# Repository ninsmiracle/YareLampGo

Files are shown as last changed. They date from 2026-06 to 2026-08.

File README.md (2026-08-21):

# YareLampGo

简体中文 | [English](README.en.md)

> 一盏能听、能看、会动、还会用表情回应你的开源桌面 AI 机械臂台灯。





<p align="center">
  YareLampGo V2.0 时间显示模式
  YareLampGo V2.0 海浪动作模式
</p>
<p align="center"><sub>V2.0 时间模式 · V2.0 海浪模式</sub></p>

YareLampGo 把电机、屏幕、RGB LED、摄像头、麦克风和大模型装进一盏台灯里。你可以在网页上控制它，也可以直接对它说话，或者让 Codex 帮你装机、排查问题和完成复杂任务。

## 它能做什么

- **会动，也会表达。** 5 自由度机械臂、动态眼睛和 RGB 点阵灯会一起回应，不是只会亮灯的普通台灯。
- **能看周围。** 摄像头可以拍照、巡看、找目标、检测人脸或有人出现；逗猫模式还能追踪彩色标记。
- **能听会说。** 支持语音识别、`Hi,小星` 唤醒、语音播报和实时语音对话。
- **表情可以自己做。** 网页里能直接画 51×9 LED 表情、上传眼睛动画；AI 也能按安全格式生成表情素材。
- **能把复杂任务交给 Codex。** 普通对话快速处理，复杂任务可转交本机 Codex；Codex 也能读取状态、看摄像头和调用台灯动作。
- **非技术用户也能玩。** 浏览器里就能聊天、控制动作、画表情、录制动作和改设置。
- **软件、固件、接线资料和 V2 结构总成已开源。** 支持二创和魔改；结构可自行拆分后 3D 打印。

## 有 Codex？让它带你装，也能让它接管任务

仓库自带两个 Codex skill：

- `$lampgo-setup`：根据你手上的硬件，一步步检查并执行安装。
- `$lampgo-control`：作为 LampGo 的“身体说明书”，让 Codex 只通过安全 MCP 观察、行动和验证真实结果。

macOS / Linux：

```bash
git clone https://github.com/ninsmiracle/YareLampGo.git
cd YareLampGo
./install-codex-skill.sh
```

Windows PowerShell：

```powershell
git clone https://github.com/ninsmiracle/YareLampGo.git
Set-Location YareLampGo
powershell -ExecutionPolicy Bypass -File .\install-codex-skill.ps1
```

然后新建一个 Codex 任务，直接说：

```text
用 $lampgo-setup 帮我安装和配置 YareLampGo V2.0
```

Skill 会自动判断你是“先体验软件”“已有成品机”还是“从零 DIY”。能安全执行的步骤它会直接做；写舵机 ID、烧录固件、首次接通 12V、校准和第一次真实运动前，它会停下来让你确认。中文用户默认全程中文。

设备已经运行时，也可以新建任务说：

```text
用 $lampgo-control 控制 LampGo 完成一个真实任务
```

控制 skill 只说明身体能力、安全边界和验证规则，不预设动作顺序。拍摄自主控制或模型横评时，它还提供同任务、同预算、无人干预的实验协议。

详细说明见 [Codex 集成](docs/guides/codex-integration.md)。

## 不用 Codex？也可以手动安装

不用 Codex，也可以完整手动安装。DIY 用户需要依次完成：安装软件 → 给五颗舵机写入 ID 1～5 → 烧录 S3/C6 → 断电组装和检查供电 → 扫描舵机 → 校准 → 配网并启动。

完整命令、安全检查和 Windows/macOS/Linux 说明见 [V2.0 手动安装、烧录与首次启动](docs/getting-started/manual-hardware-setup.md)。Windows x64 从零装机可直接按 [Windows x64 硬件完整流程](docs/getting-started/windows-hardware-flow.md) 执行。固件烧录以独立的 [YareLampGo_esp32](https://github.com/shelly-tang/YareLampGo_esp32) 仓库为准。

## 只想先看看软件

没有硬件也能运行 Web 控制台：

```bash
./install.sh
uv run lampgo onboard
uv run lampgo run --web --no-hw
```

浏览器打开 <http://127.0.0.1:8420>。Windows 安装命令和真实硬件装机步骤见 [快速上手](docs/getting-started/quick-start.md)。

## 常用命令

```bash
uv run lampgo help                 # 查看 CLI 说明和可复制示例
uv run lampgo detect               # 发现串口、摄像头和 ESP32
uv run lampgo setup-motors         # 自动选择或提示选择电机 COM，交互写入 ID
uv run lampgo scan-motors --auto-detect --ids 1-5
uv run lampgo ping --auto-detect
uv run lampgo calibrate --auto-detect # 交互式校准 5 个关节
uv run lampgo run --web            # 启动真实台灯和 Web 控制台
uv run lampgo run --web --no-hw    # 无硬件体验
uv run lampgo status               # 查看正在运行的服务
uv run lampgo clear                # 结束残留进程并释放电机扭矩
```

`setup-motors`、`scan-motors`、`ping` 和 `calibrate` 会优先使用显式的 `--port`，其次使用已保存的电机端口，最后自动检测。需要忽略旧配置并强制重扫时，使用 `--auto-detect`（或同义参数 `--rescan`）。多个 COM 口无法安全区分时，程序会列出候选让你确认，不会盲目写入舵机 ID。

更多参数：`uv run lampgo <command> --help`。

## 复刻 V2.0

V2.0 已直接替换 V1.0，请不要混用两代结构件、接线图或校准文件。

| 你需要的资料 | 入口 |
| --- | --- |
| Windows x64 从零装机、COM 自动检测和首次验收 | [Windows x64 硬件完整流程](docs/getting-started/windows-hardware-flow.md) |
| V2 硬件、组装和首次上电 | [V2.0 硬件与组装](docs/hardware/v2/README.md) |
| 电源、S3/C6、功放、LED 和舵机接线 | [V2.0 接线表](docs/hardware/wiring.md) |
| 完整 STEP 总成 | [V2.0 结构件](assets/printable/README.md) |
| GitHub 网页版图文组装说明 | [组装说明 Markdown](docs/hardware/v2/YareLampGo_V2.0_assembly_manual.md) |
| 原始图文组装说明 | [组装 DOCX 下载](docs/hardware/v2/YareLampGo_V2.0_assembly_manual.docx) |
| S3/C6 固件 | [YareLampGo_esp32](https://github.com/shelly-tang/YareLampGo_esp32) |

当前公开的是完整 STEP 总成，不是已经拆好的逐件 STL/3MF；电路 PNG 也是接线和走线参考，不是可以直接交给板厂的 Gerber 制板包。

## 现在可以玩什么

| 玩法 | 它会做什么 |
| --- | --- |
| [时间模式](docs/images/readme/lampgo_v2_time_mode.gif) | 点阵屏显示时间，顶部屏幕同步显示眼睛表情。 |
| [海浪模式](docs/images/readme/lampgo_v2_wave_mode.gif) | 灯头左右摆动，灯光和眼睛跟着联动。 |
| 逗猫模式 | 摄像头追踪逗猫棒上的彩色标记，根据标记附近的动作做出追踪、停顿和撤离。 |
| 音乐律动 | macOS 上可以跟随系统音频做动作。 |
| 自定义玩法 | 手动录制动作，再把动作、表情、灯光和语音组合成自己的 skill。 |

时钟、海浪和逗猫是已有能力；无声提醒、欢迎回家等场景可以继续用组合 skill 扩展。

## Codex 不只负责安装

启动 LampGo 后，它会自动发现本机 Codex 并注册 MCP 工具，不需要手动填 token 或端口：

```bash
uv run lampgo run --web
```

- 可以直接说“把 Codex 叫来”，把当前任务交给本机 Codex。
- Codex 可以读取台灯状态、调用安全动作、抓取摄像头画面或向你提问。
- `$lampgo-control` 会先验证真机、校准、急停和忙闲状态；调用成功但硬件跳过时不会冒充真实动作。
- LampGo 可以参考 Codex 的记忆摘要，也能在确认后导入 Agent 的资料和核心记忆。
- 其他 Agent 可以通过 CLI、HTTP / WebSocket API 或技能层继续接入。

## 它怎么工作

```mermaid
flowchart LR
  user["用户 / Codex"] --> entry["Web / 语音 / CLI"]
  entry --> skills["技能与任务路由"]
  skills --> safety["运动规划与安全检查"]
  safety --> hardware["电机 / 屏幕 / LED / 摄像头 / 音频"]
```

真实动作都会经过 `MotionRuntime` 和 `SafetyKernel`，再写入电机。架构细节见 [系统架构](docs/architecture.md)。

## 文档

| 想做什么 | 看这里 |
| --- | --- |
| 第一次运行 | [快速上手](docs/getting-started/quick-start.md) |
| 手动安装、烧录、舵机编号和首次上电 | [V2.0 手动安装](docs/getting-started/manual-hardware-setup.md) |
| 修改模型、语音、摄像头和设备配置 | [配置说明](docs/getting-started/configuration.md) |
| 做动作、表情和组合玩法 | [动作与表情](docs/guides/motion-and-expression.md) · [组合技能](docs/composed_skills.md) |
| 接入 Codex | [Codex 集成](docs/guides/codex-integration.md) |
| 了解项目代码 | [系统架构](docs/architecture.md) · [项目说明](docs/project_description.md) |
| 参与开发 | [贡献指南](docs/development/contributing.md) |

## 参与贡献

欢迎分享动作录制、表情、组合 skill、硬件改造和真实使用案例。一个 PR 尽量只做一件事；涉及真实硬件时，请说明使用的设备、校准、动作结果和是否测试过 `--no-hw`。

YareLampGo 是独立项目。电机控制链路使用 `lerobot[feetech]`，少量 HAL 集成工作受 LeLamp 启发，具体归属见 [NOTICE](NOTICE)。

## License

软件代码使用 [GPL-3.0-only](LICENSE)。作者与归属见 [AUTHORS.md](AUTHORS.md)、[COPYRIGHT](COPYRIGHT) 和 [NOTICE](NOTICE)。

硬件、结构、3D 模型、演示 GIF 和其他资产的许可单独列在 [ASSET_LICENSES.md](ASSET_LICENSES.md)。生产 CAD、供应商图纸、报价和工艺文件不在公开范围内，除非文件被明确列入资产许可表。

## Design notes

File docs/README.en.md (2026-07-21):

# YareLampGo Docs

[简体中文](README.md) | English

This index collects public docs for open-source users. YareLampGo turns a robotic desk lamp from lab-style hardware into a desktop companion that developers, creators, and hobbyists can make listen, see, move, and respond.

The public project name is **YareLampGo**. The `lampgo` name remains the internal short name for the CLI command, Python package, and config directory.

The root [README.md](../README.md) / [README.en.md](../README.en.md) is the quick landing page. Longer setup, configuration, motion, Codex, and development notes live under `docs/`.

Translation is being added gradually. Chinese is the default documentation language. English pages use the `README.en.md` filename convention, while deeper docs may remain Chinese until they are high enough priority to translate.

## Getting Started

| Doc | Use it for |
| --- | --- |
| [Quick Start](getting-started/quick-start.md) | First install, Web UI launch, no-hardware mode, and real hardware startup. |
| [Manual V2.0 Setup](getting-started/manual-hardware-setup.en.md) | Servo IDs, S3/C6 flashing, first power, and calibration without Codex. |
| [Configuration](getting-started/configuration.md) | `~/.lampgo/config.toml`, environment variables, credentials, and common config fields. |

## Guides

| Doc | Use it for |
| --- | --- |
| [Motion and Expression](guides/motion-and-expression.md) | Built-in motions, CSV recording/playback, LED expressions, and composed skills. |
| [Codex Integration](guides/codex-integration.md) | Zero-config local Codex handoff and LampGo MCP tools. |
| [V2.0 Hardware and Assembly](hardware/v2/README.en.md) | V2.0 electrical/PCB images, assembly guide, wiring, STEP, and first-power flow. |

## Architecture And Background

| Doc | Use it for |
| --- | --- |
| [Architecture](architecture.md) | IntentRouter, SkillExecutor, MotionRuntime, SafetyKernel, and HAL layering. |
| [Project Description](project_description.md) | Project background, capability boundary, and technical direction. |
| [Roadmap](roadmap.en.md) | Replaceable head modules, algorithm extension points, and future community work. |
| [Composed Skills](composed_skills.md) | User skill / composed skill data format and execution rules. |
| [Hardware And Asset Scope](hardware-and-assets-scope.md) | License boundary for software, firmware, 3D visualization assets, community printable files, and supplier production materials. |
| [Structure Files](../assets/printable/README.en.md) | V2.0 STEP AP214 complete assembly, preview, and fabrication limits. |

## Examples And References

| Path | Contents |
| --- | --- |
| [`examples/basic_motion.py`](../examples/basic_motion.py) | Basic motion control example. |
| [`examples/custom_skill.py`](../examples/custom_skill.py) | Custom skill example. |
| [`lampgo/mcp_stdio.py`](../lampgo/mcp_stdio.py) | Local MCP entrypoint used by Codex to call lamp capabilities. |

## Translation Policy

Chinese is the default documentation language. Default `README.md` files should stay Chinese, and English entry points should use the same-folder `README.en.md` convention. Key onboarding docs should be translated first; deeper design notes can stay in one language until there is enough demand. When changing a bilingual doc, mention in the PR whether the matching translation was updated or is pending.

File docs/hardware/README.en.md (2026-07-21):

# Hardware Guide

[简体中文](README.md) | English

V2.0 is the only maintained public YareLampGo hardware and mechanical version. V1.0 wiring, structure, and calibration data are no longer the main line and must not be mixed with V2.0.

## Current entry points

| File | Purpose |
| --- | --- |
| [V2.0 hardware and assembly](v2/README.en.md) | Release contents, six electrical/PCB image explanations, assembly order, first power, and V1 migration. |
| [V2.0 wiring](wiring.md) | Searchable 12V/+5V, S3/C6, amplifier, LED, and five-servo wiring tables. |
| [V2.0 assembly guide (web, Chinese)](v2/YareLampGo_V2.0_assembly_manual.md) | GitHub-readable BOM, wiring, fabrication, and assembly images. |
| [V2.0 assembly manual (DOCX download)](v2/YareLampGo_V2.0_assembly_manual.docx) | Original illustrated file for offline viewing or printing. |
| [V2.0 STEP structure](../../assets/printable/README.en.md) | Complete STEP AP214 assembly, preview, and usage limits. |
| [Source manifest](v2/SOURCE_MANIFEST.md) | Original names, SHA-256 values, inspection results, and publication limits. |
| [Hardware and asset scope](../hardware-and-assets-scope.md) | Licensing and publication boundary. |

## Important boundary

The PNGs explain nets, interfaces, placement, and PCB routing; they are not Gerber, drill, placement, or production-BOM files. The complete STEP is an assembly reference, not a per-part STL/3MF package. Makers remain responsible for fabrication, electrical, and first-power engineering checks.

See [ASSET_LICENSES.md](../../ASSET_LICENSES.md) for the exact asset licenses.

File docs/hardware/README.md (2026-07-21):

# 硬件公开资料

简体中文 | [English](README.en.md)

V2.0 是 YareLampGo 当前唯一维护的公开硬件和机械结构版本。V1.0 接线图、结构件与校准数据不再作为主线，也不能和 V2.0 混用。

## 当前入口

| 文件 | 说明 |
| --- | --- |
| [V2.0 硬件与组装](v2/README.md) | 发布内容、六张电路/PCB 图说明、装配顺序、首次上电和 V1 迁移。 |
| [V2.0 接线表](wiring.md) | 12V/+5V 电源域、S3/C6、功放、LED 和五颗舵机的可搜索接线表。 |
| [V2.0 组装说明（网页）](v2/YareLampGo_V2.0_assembly_manual.md) | 可直接在 GitHub 阅读的物料、线路、加工和组装图。 |
| [V2.0 组装说明（DOCX 下载）](v2/YareLampGo_V2.0_assembly_manual.docx) | 原始图文文件，适合离线查看或打印。 |
| [V2.0 STEP 结构件](../../assets/printable/README.md) | 完整 STEP AP214 总成、预览和使用边界。 |
| [源文件清单](v2/SOURCE_MANIFEST.md) | 原始文件名、SHA-256、文件检查结果和公开资料限制。 |
| [硬件与资产范围](../hardware-and-assets-scope.md) | 许可和发布边界。 |

## 重要边界

电路 PNG 用于理解网络、接口、器件位置和 PCB 走线，不是 Gerber/钻孔/坐标/生产 BOM。完整 STEP 是装配参考总成，不是已经拆好的逐件 STL/3MF。任何制造、制板和首次上电都需要制作者自行完成工程复核。

具体授权以仓库根目录的 [ASSET_LICENSES.md](../../ASSET_LICENSES.md) 为准。

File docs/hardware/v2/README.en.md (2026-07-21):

# YareLampGo V2.0 Hardware and Assembly

[简体中文](README.md) | English

V2.0 is the only maintained public hardware and mechanical version. Because V1.0 had very limited adoption, this release replaces the old structure and wiring entry points instead of supporting mixed V1/V2 assemblies.

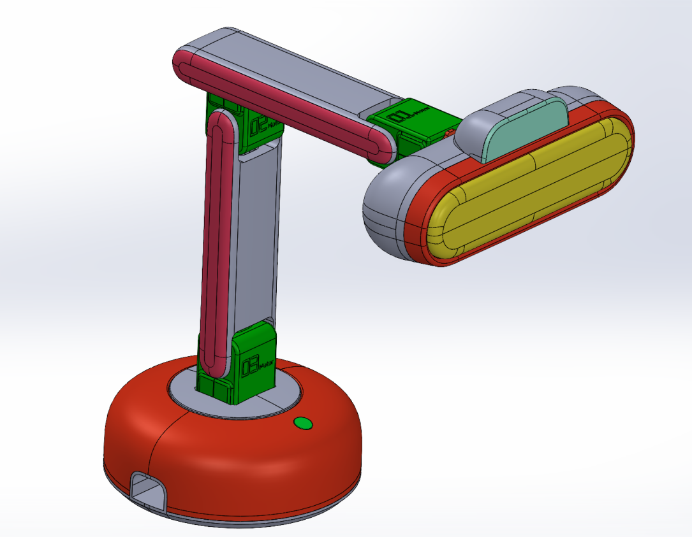
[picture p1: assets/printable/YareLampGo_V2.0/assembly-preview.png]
YareLampGo V2.0 assembly


## Release contents

| Artifact | Purpose |
| --- | --- |
| [Manual setup, flashing, and first start](../../getting-started/manual-hardware-setup.en.md) | Complete flow from servo IDs and S3/C6 flashing through calibration and Web startup. |
| [Complete STEP assembly](../../../assets/printable/YareLampGo_V2.0/YareLampGo_V2.0_assembly.step) | Structural relationships and purchased-component reference geometry; units are millimetres. |
| [GitHub-readable assembly guide (Chinese)](YareLampGo_V2.0_assembly_manual.md) | Full BOM, wiring, fabrication, and assembly images in the browser. |
| [Assembly manual DOCX download](YareLampGo_V2.0_assembly_manual.docx) | Original illustrated file for offline viewing or printing. |
| [Current wiring guide](../wiring.md) | Searchable power, S3/C6, audio, LED, and servo wiring tables. |
| [`schematics/`](schematics/) | Four schematic/interface images and top/bottom PCB reference views. |
| [Source manifest](SOURCE_MANIFEST.md) | Original names, checksums, STEP/DOCX/GIF inspection results, and publication limits. |

## Current V2.0 unit demos

<p align="center">
  YareLampGo V2.0 time display mode
  YareLampGo V2.0 wave motion mode
</p>

- **Time mode:** the front matrix displays the time while the C6 screen shows an eye expression, demonstrating the current display chain and V2.0 physical design.
- **Wave mode:** the head sweeps from side to side while the front light shows a blue bar, demonstrating calibrated joint motion coordinated with light and expression output.

These GIFs show the current V2.0 unit; they are not evidence of clock accuracy, full-range joint safety, endurance, or electrical certification. Every reproduced unit still needs its own servo scan, calibration, and motion-envelope check.

## V2.0 architecture

- Seeed Studio XIAO ESP32-S3 Sense for camera, audio, LED, network, and host communication.
- ESP32-C6-LCD-1.47 display connected to the S3 over UART.
- Five STS3215 bus servos using IDs 1 through 5.
- On-board MAX98357A audio design plus an H4 five-pin compatible amplifier-module footprint; CN7 drives the speaker.
- U3 LED connector with two +5V contacts, two ground contacts, and `DIN`.
- A 12V servo domain and a +5V logic/audio/LED domain with a shared ground.

## Electrical image map

| Image | What it establishes |
| --- | --- |
| [`01-xiao-esp32-s3-pinout.png`](schematics/01-xiao-esp32-s3-pinout.png) | GPIO1 BCLK, GPIO2 LRCLK, GPIO3 LED DIN, GPIO4 amplifier data, GPIO43/44 C6 UART, +5V/GND. |
| [`02-esp32-c6-lcd-headers.png`](schematics/02-esp32-c6-lcd-headers.png) | Crossed S3/C6 UART on U1 and VBUS/GND on U2. |
| [`03-max98357a-amplifier.png`](schematics/03-max98357a-amplifier.png) | MAX98357A power, I2S, shutdown pull-up, speaker output, and module-compatible header. |
| [`04-led-board-connector.png`](schematics/04-led-board-connector.png) | U3: GND, GND, DIN, +5V, +5V from pins 5 to 1. |
| [`05-main-board-top.png`](schematics/05-main-board-top.png) | Top-side placement and routing reference. |
| [`06-main-board-bottom.png`](schematics/06-main-board-bottom.png) | Bottom-side routing and copper reference. |

The PNGs are review aids, not a board-house package. They do not include editable EDA source, Gerbers, drill data, placement coordinates, stack-up, stencil data, a production BOM, or an electrical test report.

## Recommended assembly order

1. Assign servo IDs 1-5 before installation, with only one unconfigured servo connected at a time. Disconnect 12V before every cable change.
2. Prepare the M2.5 heat-set inserts/fasteners, M3 joint fasteners, and self-tapping screws shown in the DOCX. Verify lengths and counts against the actual parts.
3. Install the servo shells with internal cable routing; keep the three mid-arm cable exits consistent and free of pinch points.
4. With 12V and USB disconnected, install the power module, base servo, main board, and base fasteners. Route cables before closing the base.
5. Assemble the support arms with M3 fasteners, passing cables through the provided holes and checking the full joint travel.
6. Install the LED board and four retaining blocks, head ring, controller, C6 display/cover, speaker, and head shells.
7. Inspect every insert, fastener, connector orientation, clearance, and cable path before applying power.

The illustrated BOM contains image-only names and does not specify every fastener length. Treat it as an assembly reference, not an unchecked production purchasing BOM.

## First power and setup

1. Remove the S3, C6, LED, and amplifier loads. Verify 12V polarity and the power module's +5V output with a multimeter.
2. Power off, reinstall logic modules, and validate S3 and C6 firmware over USB separately.
3. Support the mechanism, keep joints away from stops, and be ready to remove 12V.
4. Install software and run read-only detection:

   ```bash
   ./install.sh
   uv run lampgo detect
   uv run lampgo scan-motors --ids 1-5
   uv run lampgo ping
   ```

5. After all five servos and directions are confirmed, back up any existing calibration and run:

   ```bash
   uv run lampgo calibrate
   uv run lampgo onboard
   uv run lampgo run --web
   ```

6. Open <http://127.0.0.1:8420>, finish 2.4 GHz Wi-Fi, LLM, voice, and Codex checks, then test a small motion before large motions.

Codex users can install the repository's [`lampgo-setup`](../../../skills/lampgo-setup/SKILL.md) skill. It offers software-only, assembled-unit, and DIY V2.0 routes and pauses before servo-ID writes, erase flashing, calibration, and first motion.

## V1.0 migration

- Do not mix V1.0 and V2.0 structural parts.
- Old wiring and print-layout images no longer represent the current board or structure.
- Existing software configuration may be used only as a field reference. Reconfirm ports, device identity, and calibration on the V2.0 unit.
- Never reuse V1.0 calibration as V2.0 calibration.

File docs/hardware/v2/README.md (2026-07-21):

# YareLampGo V2.0 硬件与组装

简体中文 | [English](README.en.md)

V2.0 是当前公开硬件和机械结构的唯一维护版本。由于 V1.0 用户量很小，本次直接替换旧结构和接线入口，不提供 V1/V2 混装兼容方案。

YareLampGo V2.0 总成

## 这次发布包含什么

| 资料 | 用途 |
| --- | --- |
| [手动安装、烧录与首次启动](../../getting-started/manual-hardware-setup.md) | 从舵机编号、S3/C6 烧录到校准和 Web 启动的完整命令流程。 |
| [完整 STEP 总成](../../../assets/printable/YareLampGo_V2.0/YareLampGo_V2.0_assembly.step) | 查看结构、装配关系和采购件占位；单位为毫米。 |
| [GitHub 网页版组装说明](YareLampGo_V2.0_assembly_manual.md) | 直接在网页查看完整物料、线路、加工和组装图片。 |
| [组装说明 DOCX 下载](YareLampGo_V2.0_assembly_manual.docx) | 原始图文文件；适合离线查看或打印。 |
| [当前接线指南](../wiring.md) | 可搜索的电源域、S3/C6、音频、LED 和舵机接线表。 |
| [`schematics/`](schematics/) | 4 张原理/接口图和 2 张 PCB 顶/底层参考图。 |
| [源文件清单](SOURCE_MANIFEST.md) | 原始文件名、SHA-256、STEP/DOCX/GIF 检查结果和发布边界。 |

## 当前 V2.0 实机展示

<p align="center">
  YareLampGo V2.0 时间显示模式
  YareLampGo V2.0 海浪动作模式
</p>

- **时间模式：** 前置点阵屏显示时间，顶部 C6 屏显示眼睛表情，用于展示当前显示链路和 V2.0 整机外观。
- **海浪模式：** 灯头左右摆动，前置灯带显示蓝色光带，用于展示校准后关节动作与灯光/表情联动。

这两段 GIF 是当前 V2.0 实机展示，不是时钟精度、关节全行程、长时间运行稳定性或电气安全测试报告。其他设备复现动作前仍需完成本机舵机扫描、校准和运动空间确认。

## V2.0 架构

- 主控：Seeed Studio XIAO ESP32-S3 Sense，负责摄像头、音频、LED、网络和上位机通信。
- 屏幕：ESP32-C6-LCD-1.47，通过 UART 与 S3 互联。
- 运动：5 颗 STS3215 总线舵机，仍使用 ID 1～5。
- 音频：MAX98357A 板载方案，并保留 H4 五针功放模块兼容接口；CN7 接喇叭。
- 灯板：U3 五针接口，包含两组 +5V/GND 和一根 `DIN`。
- 供电：舵机侧为 12V，S3/C6/功放/LED 为 +5V，全部共地。

## 电路图说明

### 1. XIAO ESP32-S3 引脚

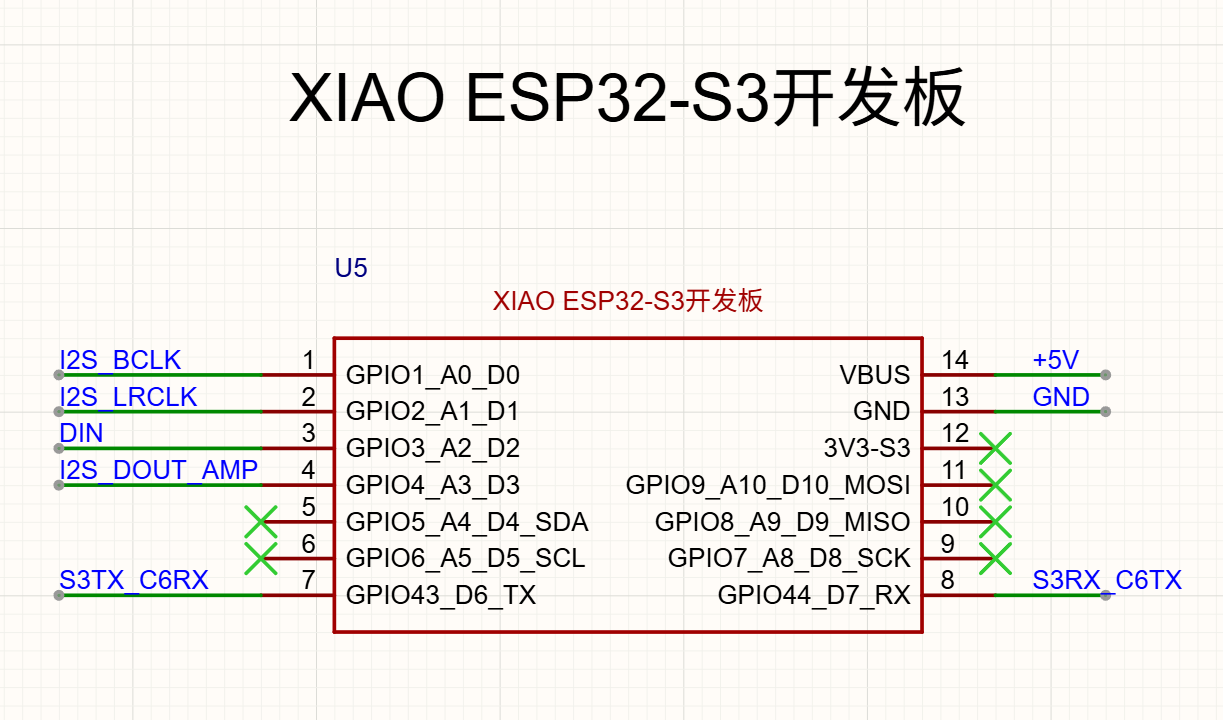
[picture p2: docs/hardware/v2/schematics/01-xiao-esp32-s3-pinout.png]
XIAO ESP32-S3 pinout


关键网络：GPIO1 为 I2S BCLK，GPIO2 为 I2S LRCLK，GPIO3 为 LED `DIN`，GPIO4 为功放 I2S 数据，GPIO43/44 为 C6 UART TX/RX。VBUS 接 +5V。

### 2. ESP32-C6 LCD 排针

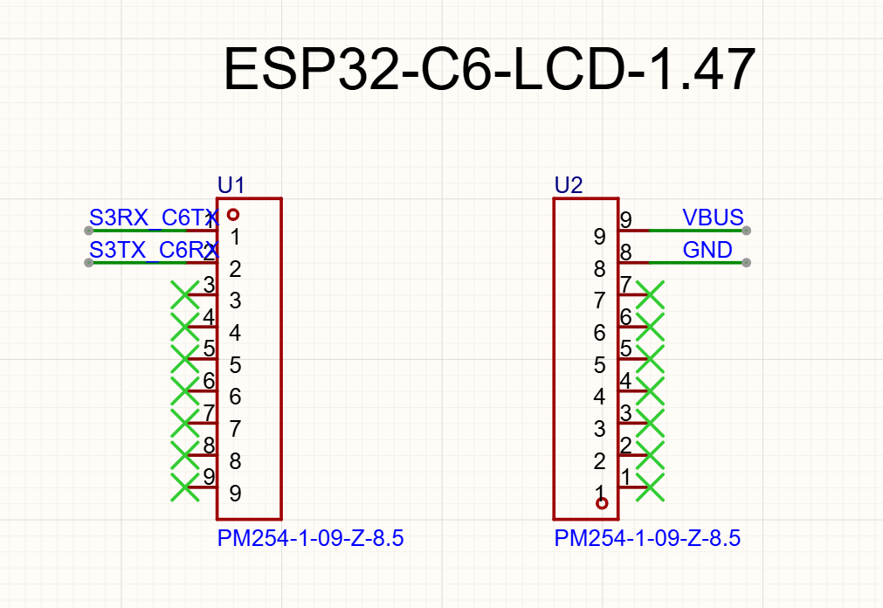
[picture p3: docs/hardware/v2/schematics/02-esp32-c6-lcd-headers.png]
ESP32-C6 LCD headers


U1 的前两针承载 S3/C6 交叉 UART；U2 的 9/8 针为 VBUS/GND。图中其余针位标记为不连接。排针网络名表达方向：`S3TX_C6RX` 是 S3 发给 C6，`S3RX_C6TX` 是 C6 发给 S3。

### 3. MAX98357A 功放

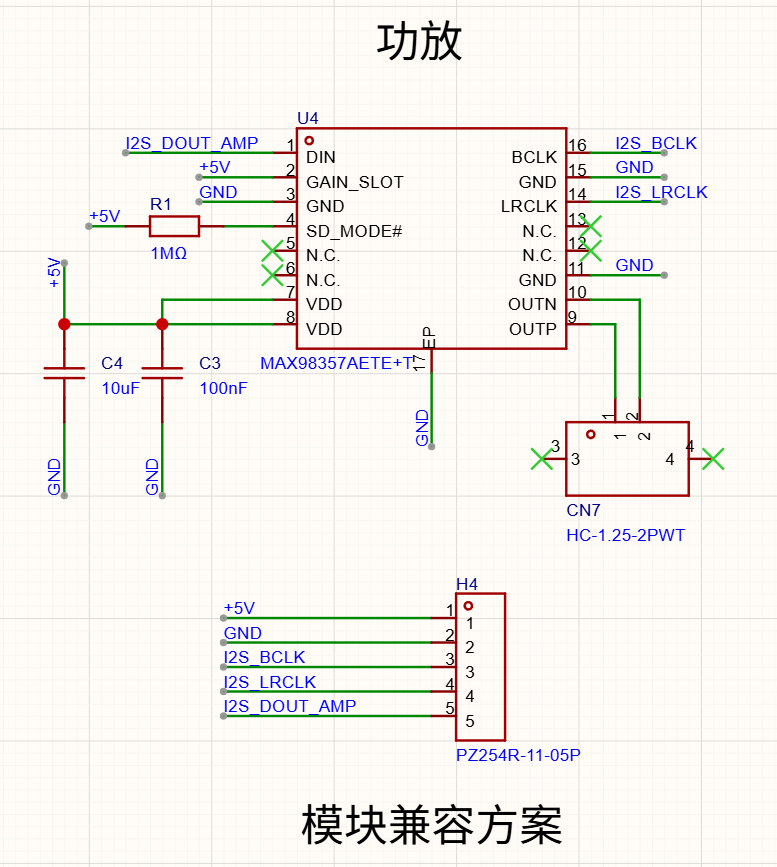
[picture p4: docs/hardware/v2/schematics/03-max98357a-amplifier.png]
MAX98357A amplifier


板载 MAX98357A 使用 +5V、BCLK、LRCLK 和 `I2S_DOUT_AMP`。`SD_MODE#` 由 1 MΩ 上拉，OUTP/OUTN 以桥接方式驱动 CN7 喇叭。H4 复用相同五个网络，用于兼容现成功放模块；不要同时装两套相互冲突的输出路径。

### 4. LED 灯板接口

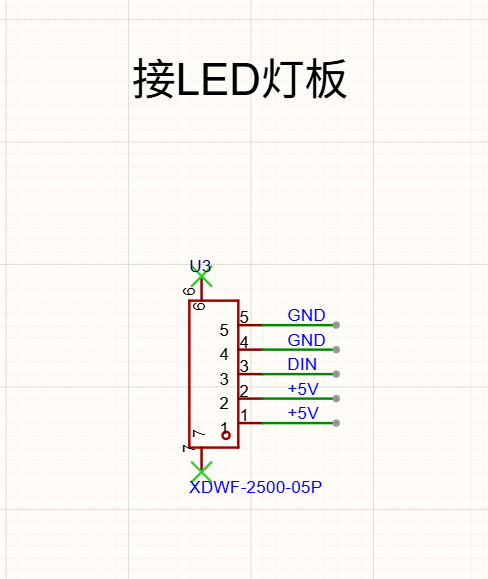
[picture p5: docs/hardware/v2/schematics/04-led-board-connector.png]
LED board connector


U3 从 5 到 1 依次为 GND、GND、DIN、+5V、+5V。此图没有定义线束插头的观察方向，压线和插接前必须对照 PCB 丝印和万用表，不要仅凭线色判断。

### 5. 主板顶层

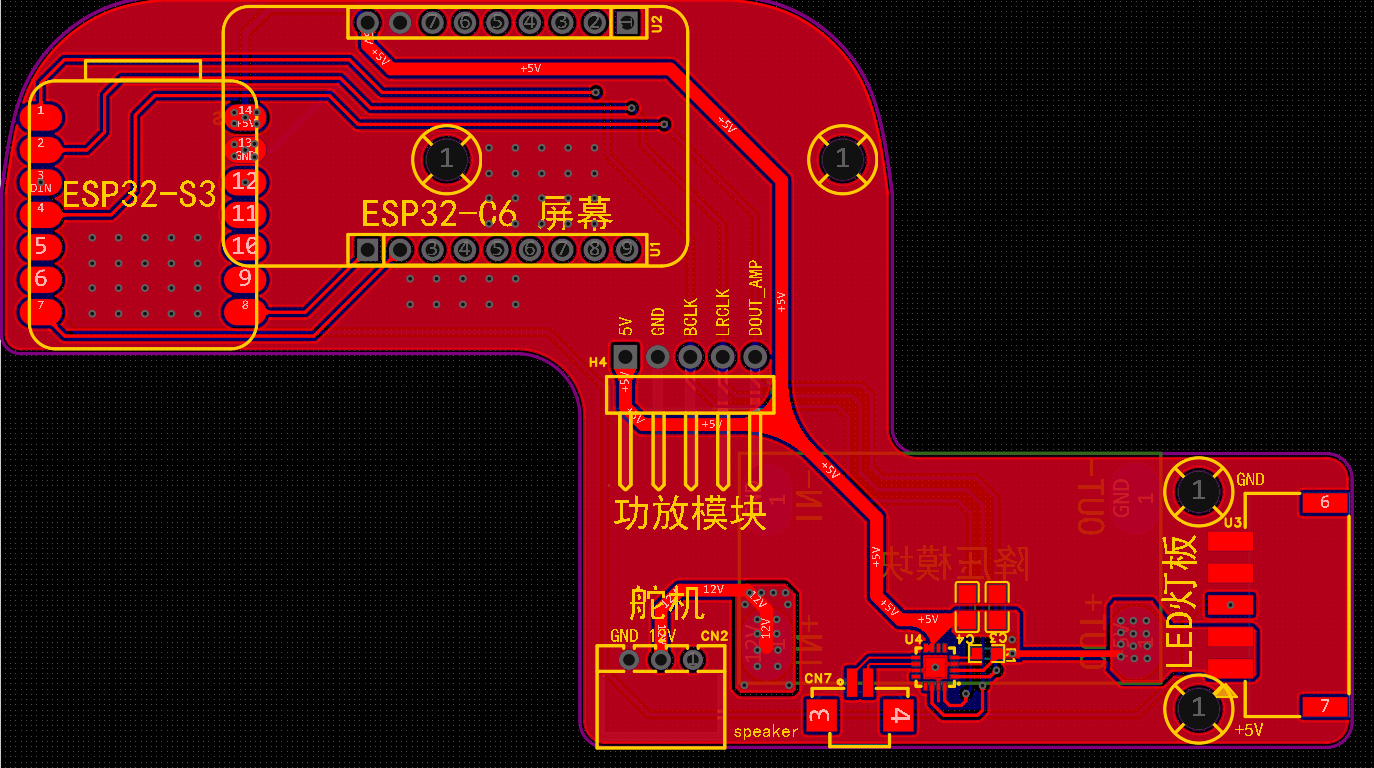
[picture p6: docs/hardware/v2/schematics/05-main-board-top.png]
Main board top


顶层图显示 S3、C6、功放模块兼容位、板载功放/喇叭、舵机、电源模块和 LED 灯板接口的相对位置。它适合做装配与连通性复核，不等同于完整制板输出。

### 6. 主板底层

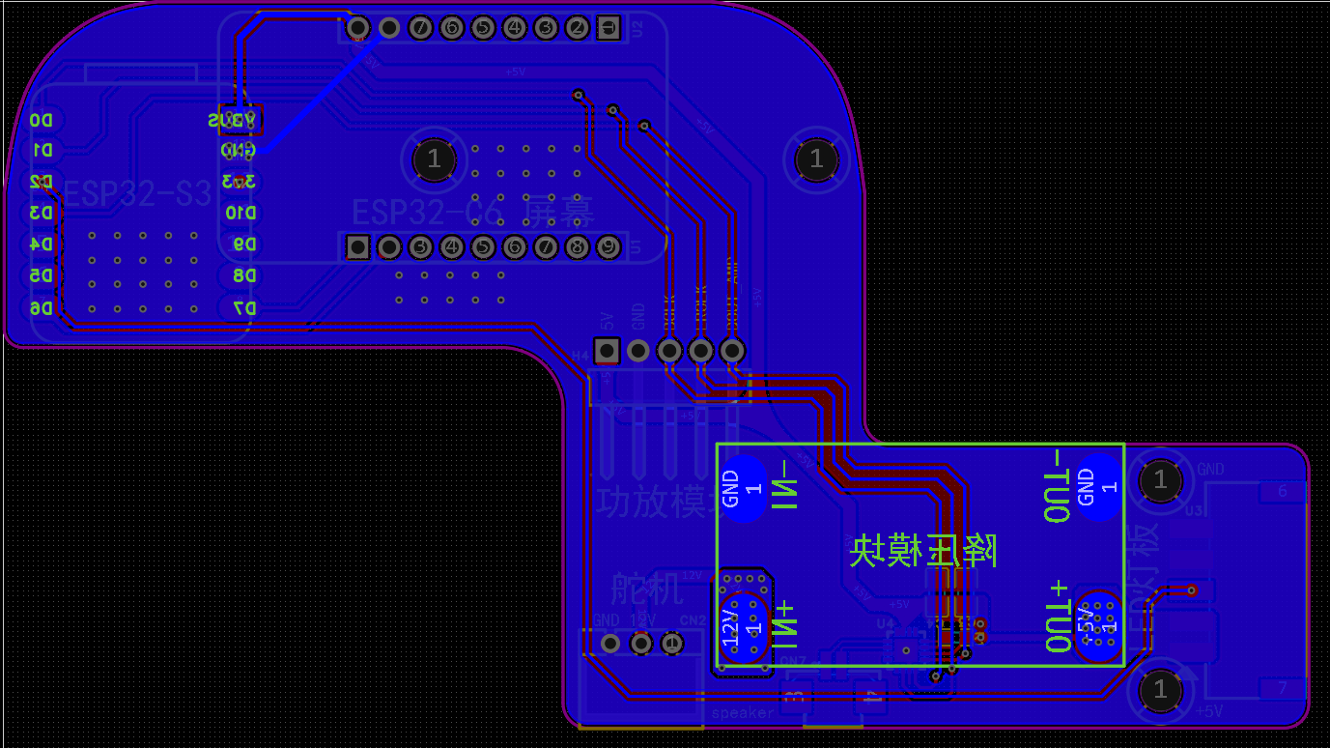
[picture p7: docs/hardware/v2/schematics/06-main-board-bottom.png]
Main board bottom


底层图用于核对底层走线、铜皮和贯穿连接。与顶层图一样，它缺少钻孔、层叠、阻焊/钢网和生产说明，不能直接交给板厂。

## 建议装配顺序

1. **先编号舵机。** 一次只连接一颗舵机，按 `base_yaw` 到 `wrist_pitch` 写入 ID 1～5；每次换线都先断 12V。
2. **准备紧固件和嵌件。** 原说明使用 M2.5 热熔铜螺母/嵌件、M2.5 紧固件、M3 关节紧固件和部分自攻螺钉。采购前在 STEP/DOCX 中复核长度与数量。
3. **装五个舵机外壳。** 舵机线留在壳体内部指定通道，三个中段舵机的线缆朝向保持一致，避免壳体夹线。
4. **装底座电子件。** 断开 12V 和 USB，安装电源模块、底座舵机、控制板和固定件；先走线，再合上底盖/上盖。
5. **装支撑杆。** 使用 M3 紧固关节，把线束穿过支撑杆走线孔；转动全行程检查是否拉扯或磨线。
6. **装灯头。** 先固定 LED 灯板及四个固定块，再装外圈、控制板、C6 屏幕/盖板、喇叭和灯头外壳。
7. **静态验收。** 逐个检查嵌件、螺钉、插头方向、活动间隙和线束夹点，再进行首次上电。

> DOCX 中物料表的大部分名称仍嵌在图片内，且没有给出全部紧固件长度。它是装配参考，不是可以不经复核直接采购的量产 BOM。

## 首次上电与软件配置

1. 不插 S3/C6/LED/功放，先验证 12V 极性和电源模块 +5V 输出。
2. 断电后装回逻辑模块；分别通过 USB 确认 S3、C6 固件可以启动。
3. 扶稳机构，关节远离限位，准备随时断开 12V。
4. 安装并执行只读探测：

   ```bash
   ./install.sh
   uv run lampgo detect
   uv run lampgo scan-motors --ids 1-5
   uv run lampgo ping
   ```

5. 五颗舵机和方向均确认后，备份已有校准，再执行：

   ```bash
   uv run lampgo calibrate
   uv run lampgo onboard
   uv run lampgo run --web
   ```

6. 打开 <http://127.0.0.1:8420>，完成 2.4GHz Wi-Fi、LLM、语音和 Codex 检查。先执行小幅动作，再尝试大幅动作。

Codex 用户可以先安装仓库自带的 [`lampgo-setup`](../../../skills/lampgo-setup/SKILL.md) skill，让 Codex 按软件、成品机或 DIY V2.0 三条路径逐步执行，并在舵机编号、擦除烧录、校准和首次运动前停下来确认。

## V1.0 迁移

- 不要混装 V1.0 与 V2.0 结构件。
- 旧接线图和旧打印摆盘图不再代表当前主板/结构。
- 已有 V1.0 软件配置可作为字段参考，但串口、设备 ID 和校准必须按 V2.0 实机重新确认。
- V1.0 校准文件不能直接用于 V2.0。重建后先扫描五颗舵机，再做完整校准。

## 当前公开资料的限制

- STEP 是完整总成，没有逐件 STL/3MF 和打印参数。
- PNG 是电路/PCB 参考图，没有 Gerber、钻孔、坐标、生产 BOM 或可编辑 EDA 源文件。
- DOCX 没有形成已签核的量产 BOM、扭矩规范或检验规范。
- 开源资料仍要求制作者自行承担加工、电气和运动安全复核。

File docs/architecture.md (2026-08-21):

# YareLampGo 架构

YareLampGo 是一个运行在 PC 上的机器人运行时。它负责把 Web UI、CLI、语音、本地 Codex 和真实硬件接到一起，并保证所有机械臂动作都先经过技能系统和安全内核。

## 总览

```text
用户 / Codex
  |
  |-- Web UI / REST / WebSocket
  |-- CLI / IPC
  |-- 语音 / LiveKit
  |-- AgentHarness / stdio MCP
  v
LampgoServer
  |
  |-- IntentRouter + LLMClient
  |-- SkillRegistry + SkillExecutor
  |-- WebGateway + IPCServer
  |-- EventBus + AgentManager
  v
设备能力
  |
  |-- MotionRuntime -> SafetyKernel -> HAL -> 5-DOF 电机
  |-- LEDController -> ESP32 LED 表情
  |-- CameraCapture -> ESP32 / 本地摄像头
  |-- WakeLoop / STT / TTS -> ESP32 / 本地麦克风和扬声器
  |-- Touch feedback -> 台灯头部触摸电容 -> 控制芯片 -> PC
```

核心原则：上层只能调用技能或接口，不能直接绕过 `MotionRuntime` / `SafetyKernel` 写电机。

## 主要入口

| 入口 | 代码 | 用途 |
| --- | --- | --- |
| CLI | `lampgo/cli.py` | 启动服务、调用技能、录制动作、校准、探测设备。 |
| IPC | `lampgo/ipc.py` | CLI 和本地脚本通过本地 IPC 调用运行中的守护进程；POSIX 使用 Unix socket，Windows 使用回环 TCP。 |
| Web UI | `lampgo/web/gateway.py` + `lampgo/web/static/` | 浏览器控制台，提供聊天、设置、录制、表情、技能和设备管理。 |
| REST / WebSocket | `lampgo/web/gateway.py` | Web UI、MCP 代理和外部程序的 HTTP / WS 接口。 |
| Codex Harness | `lampgo/agent/`、`lampgo/mcp_stdio.py` | 启动复杂任务，并把台灯能力暴露为 Codex MCP 工具。 |
| 语音 | `lampgo/voice/` | 唤醒词、语音输入、LiveKit 会话、STT 和 TTS。 |

## 请求流

### 简单指令

```text
用户输入 "点头"
  -> IntentRouter 关键词命中
  -> SkillExecutor 调用 nod
  -> MotionRuntime 生成/播放轨迹
  -> SafetyKernel 校验每一帧
  -> HAL 写入电机
```

适合点头、摇头、回安全位、切表情、播放录制动作等高频操作。

### 复杂指令

```text
用户输入复杂需求
  -> IntentRouter 未命中关键词
  -> LLMClient 进入工具调用循环
  -> 调用技能 / 摄像头 / 联网搜索 / say / finish_response
  -> 本地能力不够时 escalate_to_agent
  -> AgentManager 通过 codex exec --json 启动本机复杂任务
  -> Codex 可经 lampgo mcp-stdio 调用台灯或请求用户确认
```

LLM 工具列表由当前 `SkillRegistry` 生成。用户保存的新组合技能会写入 `~/.lampgo/skills/user/` 并热加载到注册表。

### 语音输入

```text
麦克风 / ESP32 音频
  -> VAD / WakeLoop / LiveKit
  -> STT 转文字
  -> 复用文本请求流
  -> TTS / Web UI 返回结果
```

`voice.mic_device = "esp32"` 或 `device_esp32.mic_enabled = true` 时，系统优先使用 ESP32 麦克风；不可用时可回退到本地麦克风。

## 运行时模块

| 模块 | 职责 |
| --- | --- |
| `LampgoServer` | 组装配置、硬件、技能、路由、IPC、Web、语音和生命周期。 |
| `EventBus` | 在技能、WebSocket、TTS、Agent 问询和状态更新之间传递事件。 |
| `AgentManager` | 保存复杂任务、选择 provider、转发 JSONL 进度并管理取消。 |
| `CodexProvider` | 自动发现/注册 Codex，以受控 sandbox 启动本机任务。 |
| `CodexMemorySummaryProvider` | 缓存并裁剪 `memory_summary.md`，为同步提示词提供有界上下文。 |
| `SkillRegistry` | 管理内置技能和用户组合技能。 |
| `SkillExecutor` | 负责技能执行、取消、超时和当前 busy 状态。 |
| `IntentRouter` | 先做关键词快路径，未命中时交给 LLM 或 AgentHarness。 |
| `LLMClient` | OpenAI / Anthropic 兼容的多轮工具调用，支持视觉、联网搜索和技能工具。 |

## 硬件与感知

| 能力 | 代码 | 说明 |
| --- | --- | --- |
| 电机 | `lampgo/core/hal.py` | Feetech 电机总线、校准、读写关节状态。 |
| 运动 | `lampgo/core/motion.py` | 50Hz 控制循环，支持目标驱动和轨迹驱动。 |
| 安全 | `lampgo/core/safety.py` | 关节限位、速度/加速度上限、急停状态。 |
| 动作风格 | `lampgo/core/style.py`、`spring.py`、`trajectory.py` | 平滑、弹簧、呼吸感、重叠动作等表达层。 |
| LED | `lampgo/core/led.py` | 本机串口或 ESP32 `/device/led` 串口桥的 LED 表情控制。 |
| ESP32 设备 | `lampgo/device/esp32.py` | mDNS 发现、健康检查、HTTP 代理、摄像头抓帧。 |
| ESP32 音频 | `lampgo/device/audio_stream.py` | 通过 WebSocket 接收 ESP32 PCM 音频。 |
| 摄像头 | `lampgo/perception/camera.py` | 优先 ESP32 摄像头，也支持本地 OpenCV 摄像头。 |
| 触摸反馈 | 台灯头部触摸电容经控制芯片上报 PC，未来可进入事件总线并触发技能。 |

## 数据与配置

| 数据 | 位置 |
| --- | --- |
| 主配置 | `~/.lampgo/config.toml` |
| API key / token | `~/.lampgo/credentials.json` |
| 用户组合技能 | `~/.lampgo/skills/user/*.json` |
| 内置录制动作 | `assets/recordings/*.csv` |
| 用户录制动作 | `assets/recordings/user/*.csv` 或自定义 `recordings_dir` |
| 设备校准 | `assets/calibration/*.json` |
| 人设与记忆 | `~/.lampgo/`、`~/.lampgo/memory/` |

配置优先级：

```text
CLI 参数 > 环境变量 / .env > ~/.lampgo/config.toml / credentials.json > 内置默认值
```

## 启动流程

```text
load_config
  -> LampgoServer(config)
  -> 连接 HAL / LED；失败则降级到 no_hw
  -> 注册内置技能
  -> 加载用户组合技能
  -> 启动 IPCServer
  -> 启动 ESP32 发现（可选）
  -> 构建 LLMClient（有 API key 时）
  -> 启动 WebGateway（--web）
  -> 自动发现 Codex 并注册 LampGo stdio MCP
  -> 启动 WakeLoop / LiveKit Agent SDK（配置完整时）
```

`--no-hw` 模式会跳过真实电机和 LED 连接，但 Web UI、配置、LLM 路由、技能列表、Codex 集成和大部分软件链路仍可运行。

## 扩展点

| 扩展方向 | 推荐方式 |
| --- | --- |
| 新动作 | 新增 `Skill`，或保存用户组合技能。 |
| 新录制 | 使用 Web UI 或 `lampgo record` 录制 CSV。 |
| 新传感器 | 先接入设备管理层，再通过 `EventBus` / 状态接口 / LLM 工具暴露。 |
| 新 Agent provider | 实现新的 provider 并接入 `AgentManager`，不要把 provider 名称写进业务层。 |
| 新 Codex 工具 | 在 `lampgo/mcp_stdio.py` 增加小型协议映射，最终仍调用 LampGo HTTP / IPC 接口。 |
| 新 UI 能力 | 在 `WebGateway` 增加 API，在 `web/static/` 增加前端交互。 |

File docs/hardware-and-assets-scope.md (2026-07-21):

# Hardware and Asset Scope

This repository primarily publishes the YareLampGo software runtime, Web UI, CLI,
Codex integration, examples, and public documentation.

## License Boundaries

- Software source code in this repository is licensed under GPL-3.0-only unless a
  file says otherwise.
- ESP32 firmware is maintained in the separate `YareLampGo_esp32` repository and
  should declare its own license.
- Asset licensing is declared in the repository-level `ASSET_LICENSES.md`.
- `assets/lampgoGLB.glb` is a Web runtime visualization asset licensed under
  CC-BY-NC-SA-4.0 for non-commercial sharing and adaptation.
- Community-printable STL/3MF/STEP/STP files, when published, should live under
  `assets/printable/` and use CERN-OHL-W-2.0 unless a local notice says
  otherwise. The current public V2.0 assembly is in
  `assets/printable/YareLampGo_V2.0/`.
- The approved V2.0 assembly DOCX and schematic/PCB reference PNGs live under
  `docs/hardware/v2/` and use the hardware-asset terms listed in
  `ASSET_LICENSES.md`.

## Public Hardware Scope

The public hardware material should be limited to what helps users build, repair,
or understand YareLampGo without exposing supplier production details:

- BOM-level component references.
- Assembly notes and safety guidance.
- Supplier purchase links for finished parts or kits.
- Public wiring, component, and assembly notes under `docs/hardware/`.
- Early public community-printable STL/3MF/STEP/STP files when the team chooses
  to publish them.

## Hardware And ID Contributors

YareLampGo's hardware, industrial design (ID), and mechanical/structural work
includes contributions from @Yue-Xiaolong, @mnw852173-star, @tian135, and
@majiachao. Their contribution scope is acknowledged here separately from the
software package name and CLI command, which remain `lampgo`.

The following material should stay outside the public repository unless it is
separately approved for release:

- Production CAD and original supplier drawings.
- STEP/SLDASM/SLDPRT files that expose supplier-only manufacturing geometry,
  except for the explicitly published community reproduction package under
  `assets/printable/`.
- Vendor quotations, process documents, tooling details, and private part
  numbers.
- Appearance or industrial-design files intended for patent, trademark, or
  supplier-only workflows, unless they are explicitly published under
  `ASSET_LICENSES.md` or a local license notice.

## Runtime 3D Assets

`assets/lampgoGLB.glb` is a Web visualization asset for the pet panel. It is used
to display motion state and is not the preferred printable or manufacturing
source file. Its license is declared in `ASSET_LICENSES.md`. If the production
design changes or the asset is derived from restricted supplier CAD, replace it
with a simplified visualization model before public release.

## Public Hardware Documentation

Public hardware assembly and wiring material lives under `docs/hardware/`.
Current public entry points:

- `docs/hardware/README.md`
- `docs/hardware/wiring.md`
- `docs/hardware/v2/README.md`
- `docs/hardware/v2/YareLampGo_V2.0_assembly_manual.md`
- `docs/hardware/v2/YareLampGo_V2.0_assembly_manual.docx`
- `docs/hardware/v2/assembly-manual-media/`
- `docs/hardware/v2/schematics/`

## Printable Appearance And Structural Files

Public printable appearance and structural files live under `assets/printable/`.
The current V2.0 STEP AP214 assembly is
`assets/printable/YareLampGo_V2.0/YareLampGo_V2.0_assembly.step`, with an
assembly preview in the same directory. It is an approved community
reproduction/reference package, not a production-approved supplier drawing set
or a print-ready per-part STL/3MF package.

The V2.0 electrical PNGs are connection/routing references. Editable EDA
source, Gerbers, drills, placement data, a production BOM, and an electrical
test report are not part of the current public package.

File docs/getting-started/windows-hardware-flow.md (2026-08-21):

# Windows x64 硬件完整流程

本文是 YareLampGo V2.0 在 Windows x64 上从零开始装机、编号、校准和首次启动的完整顺序。
如果你只想先体验软件，可以跳过本文，执行 `uv run lampgo run --web --no-hw`。

## 全流程总览

不要把下表中的命令一次性整段执行。每一阶段都必须先满足“通过标准”，失败时按“停止点”处理后才能继续。

| 阶段 | 是否带电 | 执行命令或操作 | 通过标准 | 失败时停止点 |
| --- | --- | --- | --- | --- |
| 1. 软件安装 | 舵机 12V 断开；USB 可不接 | `powershell -ExecutionPolicy Bypass -File .\install.ps1 --dev`、`uv run pytest -q` | Python、LampGo CLI 和测试均通过 | 不接硬件，先修复安装或测试错误 |
| 2. COM 识别 | 先只接 USB；需要主动探测时再给单颗舵机供 12V | `uv run lampgo detect` | 唯一识别或人工确认电机适配器 COM 口 | 多个候选未确认时禁止写 ID |
| 3. 舵机写 ID | 每次只接一颗舵机；按提示切换 12V | `uv run lampgo setup-motors --auto-detect` | 五颗舵机分别写成 ID 1～5 | 任一颗失败时断开 12V，不连接下一颗 |
| 4. 编号复核 | 五颗舵机接回总线并供 12V | `uv run lampgo scan-motors --auto-detect --ids 1-5`、`uv run lampgo ping --auto-detect` | ID 1～5 各有且只有一个稳定响应 | 缺失、重复、掉线时禁止校准 |
| 5. S3/C6 固件 | 舵机 12V 断开；目标板按固件说明使用 USB | Arduino IDE 或固件仓库提供的烧录流程 | 两块板可启动，摄像头、音频、LED、UART、Wi-Fi 基础链路正常 | 板型、Flash、PSRAM 或串口不确定时禁止组装上电 |
| 6. 断电组装 | 12V 和所有 USB 全断开 | 按 V2.0 结构与接线文档组装 | 极性、针序、共地、线束和紧固件全部复核 | 任何短路、反接、夹线风险都必须先排除 |
| 7. 电源轨检查 | 先拆逻辑模块，只给电源板 12V | 万用表测量 +5V 对 GND | 电压约为设计值 +5V、极性正确、无异常发热 | 电压或极性异常立即断开 12V |
| 8. 校准 | 整机供电，运动范围清空 | 先备份，再运行 `uv run lampgo calibrate --auto-detect --id AL02` | 生成或更新 `assets/calibration/AL02.json`，过程无碰撞和硬限位 | 方向异常、卡顿、异响或掉线立即急停/断电 |
| 9. 首次启动 | 整机供电，手边保留 12V 开关 | `uv run lampgo onboard`、`uv run lampgo run --web --no-home` | `status` 显示硬件连接正常，Web 控制台可打开 | 服务、IPC 或硬件状态异常时禁止动作测试 |
| 10. 小动作验收 | 整机供电，扶稳机构 | 每个关节只移动 3°、速度 15，再 `return_safe` | 五个关节方向、幅度、线束和噪声正常 | 任一异常立即 `uv run lampgo estop`，必要时断 12V |
| 11. 外设验收 | 整机供电 | LED、时钟、摄像头、麦克风、音频命令 | 各外设单项通过且不会影响电机通信 | 串口占用、过热或供电波动时停止整机测试 |
| 12. 退出清理 | 先停止服务，再按需保留 12V 释放扭矩 | 服务窗口 `Ctrl+C`，必要时 `uv run lampgo clear` | 进程退出、端口释放、舵机不再保持扭矩 | 无法确认安全状态时直接断开 12V |

## 现场验收清单

- [ ] 安装脚本完成，`uv run lampgo --help` 正常。
- [ ] 全量软件测试通过，并记录提交版本。
- [ ] 已确认电机适配器 COM 口；多个 COM 口时没有依赖猜测。
- [ ] 五颗舵机按机械位置写入 ID 1～5。
- [ ] `scan-motors` 和 `ping` 均确认 ID 1～5 稳定在线。
- [ ] S3 和 C6 固件、板型、Flash/PSRAM 选项和各自 COM 口已记录。
- [ ] 断电状态下完成极性、共地、针序、线束和短路检查。
- [ ] 拆下逻辑模块时实测 +5V 对 GND 正常。
- [ ] 原校准文件已备份，新校准文件路径已记录。
- [ ] 首次启动使用 `--no-home`，服务和硬件状态正常。
- [ ] 五个关节的小角度动作和回安全位均通过。
- [ ] 软件急停和物理断电路径均已确认。
- [ ] LED、摄像头、麦克风、扬声器/音频链路逐项通过。
- [ ] 退出后相关进程、IPC 端口和舵机扭矩均已释放。

## 0. 安全边界

开始前请准备：

- Windows 10/11 x64、Python 3.12+ 和 PowerShell。
- 一个可断开的 12V 电源开关。
- 万用表。
- 空旷、不会夹手或碰撞的机械臂运动范围。

必须遵守：

- 改舵机线、写舵机 ID 或切换舵机时，先断开 12V。
- 写 ID 时总线上只能有一颗舵机。
- 新板先拆下 S3、C6、LED 和功放，确认 +5V 后再装逻辑模块。
- 不要在未确认防反灌设计前，同时用 USB 和外部 +5V 给同一模块供电。
- 第一次真实运动前，扶稳机构并准备随时急停或断开 12V。

## 1. 安装软件

**前置条件：** 舵机 12V 断开，PowerShell 位于仓库根目录；首次安装需要网络。

在 PowerShell 中进入项目根目录：

```powershell
Set-Location 'C:\Users\你的用户名\Downloads\YareLampGo-main'
powershell -ExecutionPolicy Bypass -File .\install.ps1 --dev
```

验证安装：

Windows 用户的主测试入口是从仓库根目录运行 `uv run pytest -q`；不要直接双击测试文件。该命令会运行项目测试，并在 Windows 环境中覆盖 Windows 兼容性测试。

```powershell
uv run python --version
uv run lampgo --help
uv run pytest -q
```

如果 `uv` 没有加入当前 PowerShell 的 PATH，可以直接使用项目虚拟环境：

```powershell
.\.venv\Scripts\python.exe --version
.\.venv\Scripts\lampgo.exe --help
```

**通过标准：** Python 版本满足 3.12+，`lampgo --help` 能显示命令，测试无失败。

**停止条件：** 安装或测试失败时不要连接舵机总线，先保存错误输出并修复软件环境。

## 2. 自动检测 COM 串口

**前置条件：** 先只连接 USB 串口适配器；关闭 Arduino 串口监视器、串口调试器和其他 LampGo 进程。

先运行只读探测：

```powershell
uv run lampgo detect
```

探测会扫描：

- Windows `COM` 串口。
- Feetech 电机总线。
- ESP32/LED 串口。
- DirectShow 摄像头。
- 麦克风输入设备。

Windows 的蓝牙虚拟串口（`BTHENUM`，常见于“蓝牙链接上的标准串行”）默认跳过，因为它们可能在打开时长时间阻塞；如果你的电机适配器确实使用蓝牙，仍可用 `--port COMx` 显式指定。

准备进入舵机编号流程、并且需要忽略旧配置重新选择电机口时，运行电机专用路径：

```powershell
uv run lampgo setup-motors --auto-detect
```

它会在真正写入 ID 前先完成端口选择，并且仍会要求每次只接一颗舵机。这个命令属于编号流程，不要把它当成纯只读探测；如果还没准备写 ID，请只运行 `lampgo detect`。

配置舵机 ID 时，默认会自动选择电机串口：

```powershell
uv run lampgo setup-motors
```

端口选择优先级如下：

1. 命令行显式指定的 `--port COM5`。
2. 已保存的 `device.motor_port` 配置。
3. 自动扫描并探测 Feetech 响应。
4. 只有一个 COM 口但半双工探测不确定时，使用该唯一端口作为候选。

如果想忽略旧配置、强制重新扫描：

```powershell
uv run lampgo setup-motors --auto-detect
```

`--rescan` 是同义写法。扫描和校准也支持强制重扫：

```powershell
uv run lampgo scan-motors --auto-detect --ids 1-5
uv run lampgo ping --auto-detect
uv run lampgo calibrate --auto-detect --id AL02
```

如果有多个 COM 口且程序无法安全区分，`setup-motors` 会列出候选并要求你选择。自动检测不会在这种情况下盲目写 ID；也可以人工确认后执行：

```powershell
uv run lampgo setup-motors --port COM5
```

**通过标准：** 程序唯一识别电机口，或你已经通过设备管理器、插拔对比和适配器标签人工确认。

**停止条件：** 非交互命令遇到多个候选会返回失败；在确认 COM 口前不得执行任何写 ID 操作。

## 3. 给五颗舵机写入 ID

**前置条件：** 已确认电机 COM 口，准备好可快速断开的 12V，并把五颗舵机按机械位置做好标签。

对应关系：

| 机械位置 | 程序名称 | 目标 ID |
| --- | --- | ---: |
| 底座水平旋转 | `base_yaw` | 1 |
| 底座俯仰 | `base_pitch` | 2 |
| 肘部俯仰 | `elbow_pitch` | 3 |
| 手腕滚转 | `wrist_roll` | 4 |
| 手腕俯仰 | `wrist_pitch` | 5 |

启动完整编号向导：

```powershell
uv run lampgo setup-motors --auto-detect
```

每个提示都执行以下顺序：

1. 断开 12V。
2. 只连接当前提示位置的一颗舵机。
3. 确认没有第二颗舵机共用总线。
4. 恢复供电并按 ENTER。
5. 等待写入成功。
6. 再次断开 12V，才允许切换下一颗舵机。

不要为每颗舵机重新启动一次五舵机向导。

**通过标准：** 向导依次报告 `base_yaw`、`base_pitch`、`elbow_pitch`、`wrist_roll`、`wrist_pitch` 写入成功。

**停止条件：** 任一步失败都先断开 12V；不要把写入状态不明的舵机接回完整总线，也不要跳过失败项继续。

## 4. 编号后的只读验证

**前置条件：** 断电后把五颗舵机全部接回总线，检查没有重复接头或松动线缆，再恢复 12V。

五颗舵机全部接回总线后，执行：

```powershell
uv run lampgo scan-motors --auto-detect --ids 1-5
uv run lampgo ping --auto-detect
```

必须满足：

- ID 1、2、3、4、5 各有一个响应。
- 没有重复 ID。
- 没有间歇性掉线。
- 型号和通信状态正常。

缺失、重复或不稳定时，不要进入校准。

**通过标准：** 扫描结果只有 ID 1～5，`ping` 中五个配置名称全部在线且无状态错误。

**停止条件：** 任一 ID 缺失、重复、间歇掉线或报告状态错误时，保持只读排查，不校准、不运动。

## 5. 烧录 S3 和 C6 固件

**前置条件：** 舵机 12V 断开；一次只选择当前要烧录的板和 COM 口，并关闭占用串口的程序。

固件位于独立的 `YareLampGo_esp32` 仓库，烧录前以该仓库当前 README 和脚本为准。

Windows 用户可以使用 Arduino IDE：

- S3 选择 `XIAO_ESP32S3`。
- 按固件仓库要求启用 OPI PSRAM。
- C6 选择 ESP32-C6，并使用 8MB Flash 配置。
- S3 和 C6 使用不同的 COM 口。

`--erase` 只用于首次安装或明确的恢复操作。擦除会清除旧 Wi-Fi 和设备绑定。

烧录成功后还要验证：

- S3 能启动。
- 摄像头能工作。
- 麦克风和扬声器链路能工作。
- LED 能响应。
- S3/C6 UART 通信正常。
- Wi-Fi 能连接。

烧录命令成功不等于整机链路已经通过。

**通过标准：** 记录 S3/C6 的固件版本或提交号，两块板重启无异常，基础外设链路能独立工作。

**停止条件：** 板型、Flash 容量、PSRAM 模式或 COM 口不能确认时，不继续烧录或带电组装。

## 6. 断电组装和电气检查

**前置条件：** 12V 与所有 USB 全部断开，电容放电后再插拔连接器。

全程断开 12V 和 USB，按 V2.0 组装文档完成机械结构。检查：

- 舵机线不会被外壳夹住、拉紧或磨损。
- S3 GPIO43 TX → C6 RX。
- S3 GPIO44 RX ← C6 TX。
- LED U3 针序与 PCB 丝印方向一致。
- 12V 舵机侧和 +5V 逻辑侧没有接反。
- 所有逻辑地共地。
- 紧固件、热熔嵌件和连接器已经固定。
- 没有松动金属可能短路 PCB。

**通过标准：** 两人复核或逐项打勾确认针序、极性、共地、线束余量和机械紧固均正确。

**停止条件：** 任何反接、夹线、裸露导体、松动金属或无法确认的接口都必须先处理，禁止上电试错。

## 7. 首次上电

**前置条件：** 完成断电检查；万用表量程和表笔位置正确；S3、C6、LED、功放暂时拆下。

1. 拆下 S3、C6、LED 和功放，只给电源模块接入 12V。
2. 用万用表确认 +5V 对 GND 的电压和极性。
3. 断电后安装逻辑模块。
4. 分别通过 USB 确认 S3/C6 可以启动。
5. 确认机械臂远离硬限位，运动范围无人无物。
6. 接入舵机 12V。
7. 先只做只读检测：

```powershell
uv run lampgo detect
uv run lampgo scan-motors --auto-detect --ids 1-5
uv run lampgo ping --auto-detect
```

五颗舵机稳定在线后，才进入校准。

**通过标准：** +5V 极性和电压正常，逻辑模块逐一上电无异常发热，五颗舵机只读检查稳定。

**停止条件：** 电压异常、冒烟、异味、异常发热、持续掉线或 USB 反向供电迹象出现时立即断开 12V 和 USB。

## 8. 备份并校准

**前置条件：** ID 1～5 只读验证通过，运动范围清空，机构被扶稳，服务进程尚未占用电机串口。

先确认当前 Lamp ID，例如 `AL02`。如果已有同名校准文件，先备份到用户目录，不要直接覆盖：

```powershell
$backup = Join-Path $env:USERPROFILE ('.lampgo\backups\calibration\' + (Get-Date -Format 'yyyyMMdd-HHmmss'))
New-Item -ItemType Directory -Force -Path $backup | Out-Null
Copy-Item .\assets\calibration\* $backup -Recurse -Force
```

从项目根目录运行：

```powershell
uv run lampgo calibrate --auto-detect --id AL02
```

也可以明确指定端口：

```powershell
uv run lampgo calibrate --port COM5 --id AL02
```

校准前必须：

- 清空运动范围。
- 扶稳机构。
- 远离机械硬限位。
- 准备急停和 12V 断电。

校准结束后确认目标文件存在，并把它与备份目录一起记录：

```powershell
Get-Item .\assets\calibration\AL02.json
```

**通过标准：** 校准命令完成，目标 JSON 文件存在，重新执行 `ping` 仍全部在线，机构没有撞限位。

**停止条件：** 方向异常、突然加速、卡顿、异响、发热或掉线时立即急停；不要覆盖备份后反复尝试。

## 9. 配置和启动真实台灯

**前置条件：** 校准完成；先关闭所有直接访问电机串口的扫描、校准和串口监视器。

使用向导配置电机、LED、摄像头和麦克风：

```powershell
uv run lampgo onboard
```

硬件步骤会再次显示自动探测到的 COM 口和推荐端口。确认无误后保存。

在启动 daemon 前最后做一次只读确认；该命令结束后再启动服务：

```powershell
uv run lampgo ping --auto-detect
```

第一次启动建议跳过自动回零，先确认服务和状态：

```powershell
uv run lampgo run --web --no-home
```

如果向导没有保存端口，再显式追加 `--motor-port COM5`，把 `COM5` 换成实际端口。

另开 PowerShell：

```powershell
uv run lampgo status
uv run lampgo skills
```

daemon 运行期间不要再用 `ping`、`scan-motors`、`calibrate` 或串口监视器直接打开同一 COM 口。如需复查，先在服务窗口按 `Ctrl+C` 完整停止。

确认 `hal_connected`、`hardware_present` 和电机状态正常后，再测试自动回零。浏览器打开：

```text
http://127.0.0.1:8420
```

Windows 的本地 TCP IPC 会自动创建 `%USERPROFILE%\.lampgo\ipc-token`，用于阻止其他本地用户直接发送电机控制命令。不要共享或手工修改该文件；如果它损坏，先停止 LampGo，再删除该文件并重新启动以生成新令牌。

**通过标准：** `status`、`skills` 和 Web 控制台正常，硬件连接状态正确，日志没有端口占用或未授权 IPC 错误。

**停止条件：** 硬件未连接、COM 被占用、IPC 启动失败或配置端口不一致时，不进入动作测试。

## 10. 第一次真实动作

**前置条件：** 五颗舵机校准与状态正常，机构远离硬限位，扶稳底座，手能立即触及 12V 开关。

一次只测一个关节、小角度、低速度：

```powershell
uv run lampgo move base_yaw=3 --velocity 15
uv run lampgo invoke return_safe
```

确认方向、幅度、线束和噪声都正常后，再逐个测试其他关节：

```powershell
uv run lampgo move base_pitch=3 --velocity 15
uv run lampgo invoke return_safe

uv run lampgo move elbow_pitch=3 --velocity 15
uv run lampgo invoke return_safe

uv run lampgo move wrist_roll=3 --velocity 15
uv run lampgo invoke return_safe

uv run lampgo move wrist_pitch=3 --velocity 15
uv run lampgo invoke return_safe
```

出现错误方向、卡顿、异响、发热、线材拉紧或接近限位时：

```powershell
uv run lampgo estop
```

如果软件急停不够快，直接断开 12V。

所有小动作通过后，再单独做一次急停验收。急停触发后不要继续发送运动命令；先检查机构状态，在服务窗口按 `Ctrl+C`，必要时断开 12V，再重新启动。

**通过标准：** 每个关节只向预期方向移动约 3°，无碰撞、卡顿、异响、明显发热或线束拉扯，`return_safe` 正常。

**停止条件：** 任一关节方向、幅度或机械状态异常时停止整机动作验收，记录该关节和现象后排查校准、装配与限位。

## 11. 外设验收

**前置条件：** 电机小动作已通过；测试过程中一次只改变一个外设变量，观察供电和串口稳定性。

按实际配置逐项验收：

- LED：`uv run lampgo invoke set_expression expression=heart`
- 时钟：`uv run lampgo invoke show_clock`
- 摄像头：Web 设置中选择 `0`、`1` 等 DirectShow 索引并查看预览。
- 麦克风：`uv run lampgo detect` 查看默认输入设备。
- 音乐处理链路：`uv run lampgo invoke dance_to_music duration=5 source=synthetic amplitude=0.1 led=false`
- Windows 系统音频：启用 Stereo Mix 或虚拟回环输入后使用 `source=system`。

**通过标准：** LED/时钟、摄像头预览、麦克风枚举、合成音频动作均可重复通过；启用外设后电机不掉线。

**停止条件：** 外设导致供电波动、USB 重连、COM 消失、明显发热或电机掉线时，停止并分开排查电源和数据链路。

## 12. 退出和清理

**前置条件：** 结束所有动作，机构处于稳定姿态，确认没有正在执行的录制或校准任务。

优先在服务窗口按 `Ctrl+C`。确认已停止后，如需释放扭矩：

```powershell
uv run lampgo clear
```

如果只想查看清理结果、并且明确不停止进程也不访问电机总线，可以使用：

```powershell
uv run lampgo clear --skip-kill --skip-release
```

这两个跳过参数组合不是安全关机，也不能证明端口或扭矩已释放。正常退出验收必须使用服务窗口 `Ctrl+C`，必要时再运行不带跳过参数的 `uv run lampgo clear`。

**通过标准：** 对正常清理流程，`lampgo status` 不再连接 daemon，端口可重新启动，舵机不保持扭矩且整机可安全断电。

**停止条件：** 如果进程、端口或扭矩状态不明，直接断开 12V；不要在未知状态下插拔舵机线。

## 常见问题

| 现象 | 处理 |
| --- | --- |
| 只有一个 COM 口但提示探测不确定 | 程序会自动采用唯一端口；确认电机供电后继续。 |
| 蓝牙 COM 没有出现在候选列表 | `BTHENUM` 虚拟口默认跳过；确认适配器类型后使用 `--port COMx`。 |
| 有多个 COM 口且没有自动选中 | 在交互提示中选择电机适配器，或使用 `--port COM5`。 |
| 旧配置指向错误 COM 口 | 使用 `--auto-detect` 或删除/修改 `device.motor_port`。 |
| `Access denied` | 关闭 Arduino 串口监视器、串口调试工具和其他 LampGo 进程。 |
| 五颗舵机都无响应 | 检查 12V、总线数据线、半双工适配器方向和波特率。 |
| 摄像头无法打开 | 关闭 Teams/微信/Zoom，依次尝试摄像头索引 `0`、`1`。 |
| 音乐模式没有系统声音 | 启用 Stereo Mix 或配置 Windows 虚拟回环输入。 |

## Windows 现场测试记录模板

将下面内容复制到 Issue、PR 评论或本地测试记录中。没有实测的项目写“未测”，不要写“通过”。

### 环境

- 测试日期：
- 测试人员：
- Git 提交：
- Windows 版本与系统类型：
- PowerShell 版本：
- Python 版本：
- 安装方式：`install.ps1 --dev` / 其他：
- 全量测试结果：

### 串口与舵机

- 电机适配器型号：
- 自动检测结果：
- 最终电机 COM 口：
- 是否有多个候选：是 / 否；人工确认方法：

| 机械位置 | 程序名称 | 目标 ID | 写入结果 | 扫描结果 | Ping 结果 | 小动作方向 |
| --- | --- | ---: | --- | --- | --- | --- |
| 底座水平旋转 | `base_yaw` | 1 |  |  |  |  |
| 底座俯仰 | `base_pitch` | 2 |  |  |  |  |
| 肘部俯仰 | `elbow_pitch` | 3 |  |  |  |  |
| 手腕滚转 | `wrist_roll` | 4 |  |  |  |  |
| 手腕俯仰 | `wrist_pitch` | 5 |  |  |  |  |

### 固件与供电

- S3 型号、COM 口、固件版本/提交：
- C6 型号、COM 口、固件版本/提交：
- S3 PSRAM 设置：
- C6 Flash 设置：
- +5V 对 GND 实测值：
- 极性检查：通过 / 未通过：
- 12V、+5V 与共地检查：通过 / 未通过：
- 异常发热、异味或 USB 反灌：无 / 有，说明：

### 校准与首次启动

- Lamp ID：
- 原校准备份目录：
- 新校准文件：
- 校准结果：
- `lampgo status` 结果摘要：
- Web 控制台：通过 / 未通过：
- IPC token 文件已生成：是 / 否：

### 功能验收

| 项目 | 结果 | 记录 |
| --- | --- | --- |
| 五关节 3° 小动作 | 通过 / 未通过 / 未测 |  |
| `return_safe` | 通过 / 未通过 / 未测 |  |
| 软件急停 | 通过 / 未通过 / 未测 |  |
| 物理 12V 断电 | 通过 / 未通过 / 未测 |  |
| LED/表情 | 通过 / 未通过 / 未测 |  |
| 时钟显示 | 通过 / 未通过 / 未测 |  |
| 摄像头 | 通过 / 未通过 / 未测 |  |
| 麦克风 | 通过 / 未通过 / 未测 |  |
| 扬声器/音频链路 | 通过 / 未通过 / 未测 |  |
| Windows 系统音频 | 通过 / 未通过 / 未测 |  |
| 退出、端口和扭矩释放 | 通过 / 未通过 / 未测 |  |

### 结论

- [ ] 全部通过，可进入日常使用。
- [ ] 有条件通过，限制与待办：
- [ ] 未通过，停止阶段：
- 日志、照片或视频位置：
- 其他异常：

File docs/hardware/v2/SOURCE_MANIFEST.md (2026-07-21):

# YareLampGo V2.0 Source Manifest

Imported on 2026-07-21 from the approved local release folder `lampgo_v2版本开源`. Repository names are stable and descriptive; original source names and SHA-256 values are retained here for traceability.

| Original source | Repository path | Original SHA-256 | Role |
| --- | --- | --- | --- |
| `台灯0714.STEP` | `assets/printable/YareLampGo_V2.0/YareLampGo_V2.0_assembly.step` | `a60c8b63b40fb4bab887589cdc75fc13c43814913ac3284d27949861a5aca277` | Complete mechanical/electronic reference assembly |
| `组装说明文档.docx` | `docs/hardware/v2/YareLampGo_V2.0_assembly_manual.docx` | `0d8b2c995de3025d4e7982e1a7d2579b1c493d8e3ab22e2cfac3ca4611a077ec` | Illustrated BOM and assembly guide |
| `时间模式.gif` | `docs/images/readme/lampgo_v2_time_mode.gif` | `e5ccac7af60e22b28439351d57f0f7327dc082c46e828a67e1d91c8855bcc1d4` | Current V2.0 time-display and eye-expression demo |
| `海浪模式.gif` | `docs/images/readme/lampgo_v2_wave_mode.gif` | `810b1b192412105d427fba2557f2eb1509e4a118452b8d4cc2f99507db6d26f4` | Current V2.0 wave-motion and light-expression demo |
| `20260721-111629.png` | `docs/hardware/v2/schematics/01-xiao-esp32-s3-pinout.png` | `51bfd95c5c1da32ba82b3a2a71426456b17d740781b20963a146ef5401cf99e9` | XIAO ESP32-S3 signal map |
| `20260721-111639.png` | `docs/hardware/v2/schematics/02-esp32-c6-lcd-headers.png` | `8dc92be3d0d19ea9ed4e914f4ea0293752e3bdcdb90ea8bc7d42daba1c7797a6` | C6 LCD header map |
| `20260721-111643.png` | `docs/hardware/v2/schematics/03-max98357a-amplifier.png` | `c1ba65aaf1e7ee2740e3a083c5f6bf23cddce8c4d0cfb6f3907070e779185f2a` | MAX98357A and module-compatible amplifier circuit |
| `20260721-111646.png` | `docs/hardware/v2/schematics/04-led-board-connector.png` | `3d40bd00ff4a880c0bf10c27a3a151d378131652333c0a01cc783aebf64d10a9` | LED board connector |
| `20260721-111650.png` | `docs/hardware/v2/schematics/05-main-board-top.png` | `a1eaeb791f46e5053938b333d9dad7ee9af9035bc5431cbf735515bd0040bb0d` | Main-board top routing/reference view |
| `20260721-111654.png` | `docs/hardware/v2/schematics/06-main-board-bottom.png` | `5c373439e5b1655c614b87cea1bcfb17cbf1d3932b1c748764b46af1991d88a6` | Main-board bottom routing/reference view |
| `组装说明文档.docx!/word/media/image42.png` | `assets/printable/YareLampGo_V2.0/assembly-preview.png` | `d9054c009be0e5ef9d9f5706bfb0c284df787058bf5e7acf5b82f5bd88aef1a9` | Extracted assembly preview |

The public DOCX copy has SHA-256 `dc1a8b7bde0bd94ab490378cba6f75ba6086543aae21045f5fcafbe3708f9b45`. It differs from the original only because publishing metadata was scrubbed: creator/last-modifier values, WPS custom identifiers, and custom-property relationships were removed. A temporary copy produced a 13-page render pixel-identical to the source; the final public file was not opened by the renderer.

`YareLampGo_V2.0_assembly_manual.md` is the GitHub-readable counterpart. Its `assembly-manual-media/` directory contains the 42 images extracted unchanged from the public DOCX; the Markdown keeps their original document order and adds links to the current safety and wiring guides.

## Structural inspection

- Format: ISO 10303-21, STEP AP214 / `AUTOMOTIVE_DESIGN`.
- Exporter: SolidWorks 2022 (`SwSTEP 2.0`).
- Units: millimetres.
- Content scan: 34 `PRODUCT` records, 42 assembly occurrences, and 203 manifold solid B-reps.
- Named content includes the base, base cover, thickened support arms, motor shells, five motor references, head parts, LED board, power board, main PCB, ESP32-C6 LCD, and Seeed Studio XIAO ESP32-S3 Sense.

The STEP is a complete reference assembly. It has not been converted into print-ready per-part STL/3MF files, and the public package does not claim production tolerances.

## Document inspection

The assembly DOCX contains 13 rendered pages, 42 inline images, and one 24-row BOM-style table. It covers the assembly overview, motor shells, base electronics, arms, cable routing, head/LED/display installation, fasteners, and final appearance.

The original DOCX is preserved because most BOM names and geometry callouts are embedded in images rather than searchable text. The Markdown guides in this directory provide the searchable safety and wiring layer.

## Media inspection

- `时间模式.gif`: 640 × 854, 10 fps, 88 frames, 8.8 seconds.
- `海浪模式.gif`: 640 × 854, 10 fps, 79 frames, 7.9 seconds.

Both repository GIFs are byte-identical copies of the approved source files. They show the current assembled V2.0 unit but do not replace calibration, motion-safety, endurance, or electrical validation.

## Electrical publication boundary

The six PNGs are schematic and PCB routing/reference images only. This release does **not** include editable schematic/PCB source, Gerber/ODB++ fabrication layers, drill files, pick-and-place coordinates, a production BOM, impedance requirements, stack-up, or an electrical test report. Do not send the PNGs directly to a board house as a fabrication package.

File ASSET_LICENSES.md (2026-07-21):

# Asset Licenses

YareLampGo software source code is licensed under `GPL-3.0-only` unless a file
says otherwise. The asset files listed here have their own license terms and are
not relicensed by the software license. The `lampgo` name is kept as an internal
package, command, configuration, and plugin identifier.

## Runtime Visualization Assets

| File | License | Notes |
| --- | --- | --- |
| `assets/lampgoGLB.glb` | Creative Commons Attribution-NonCommercial-ShareAlike 4.0 International (`CC-BY-NC-SA-4.0`) | Web UI runtime visualization asset. Non-commercial sharing and adaptation are allowed. Commercial use requires separate permission. |
| `docs/images/readme/lampgo_v2_*.gif` | Creative Commons Attribution-NonCommercial-ShareAlike 4.0 International (`CC-BY-NC-SA-4.0`) | Current V2.0 physical-unit time and wave demonstration clips. |

Attribution: Copyright (C) 2026 @ninsmiracle, @shelly-tang, @Yue-Xiaolong,
@mnw852173-star, @tian135, @majiachao, and YareLampGo contributors.

License URL: <https://creativecommons.org/licenses/by-nc-sa/4.0/>

`CC-BY-NC-SA-4.0` covers copyright and similar rights in the visualization
asset. It allows non-commercial redistribution and adaptations, requires
attribution, and requires shared adaptations to use the same license. It does not
grant patent or trademark rights.

## Printable Hardware Assets

Community-printable YareLampGo hardware files, including published STL, 3MF,
STEP, and STP files, should be placed under `assets/printable/` and licensed
under the CERN Open Hardware Licence Version 2 - Weakly Reciprocal
(`CERN-OHL-W-2.0`) unless a local notice says otherwise.

If a future printable file is intentionally limited to non-commercial use, list
that file separately with a non-commercial asset license instead of using this
default open-hardware license.

| File pattern | License | Notes |
| --- | --- | --- |
| `assets/printable/**/*.stl` | CERN Open Hardware Licence Version 2 - Weakly Reciprocal (`CERN-OHL-W-2.0`) | Community-printable hardware design files. |
| `assets/printable/**/*.3mf` | CERN Open Hardware Licence Version 2 - Weakly Reciprocal (`CERN-OHL-W-2.0`) | Community-printable hardware design files. |
| `assets/printable/**/*.STEP` | CERN Open Hardware Licence Version 2 - Weakly Reciprocal (`CERN-OHL-W-2.0`) | Public appearance and structural source files for community reproduction. |
| `assets/printable/**/*.step` | CERN Open Hardware Licence Version 2 - Weakly Reciprocal (`CERN-OHL-W-2.0`) | Public appearance and structural source files for community reproduction. |
| `assets/printable/**/*.STP` | CERN Open Hardware Licence Version 2 - Weakly Reciprocal (`CERN-OHL-W-2.0`) | Public appearance and structural source files for community reproduction. |
| `assets/printable/**/*.stp` | CERN Open Hardware Licence Version 2 - Weakly Reciprocal (`CERN-OHL-W-2.0`) | Public appearance and structural source files for community reproduction. |
| `assets/printable/YareLampGo_V2.0/*.png` | CERN Open Hardware Licence Version 2 - Weakly Reciprocal (`CERN-OHL-W-2.0`) | Preview images for the V2.0 public structure package. |
| `docs/hardware/v2/schematics/*.png` | CERN Open Hardware Licence Version 2 - Weakly Reciprocal (`CERN-OHL-W-2.0`) | V2.0 schematic, connector, and PCB-routing reference images; not fabrication outputs. |
| `docs/hardware/v2/assembly-manual-media/*` | CERN Open Hardware Licence Version 2 - Weakly Reciprocal (`CERN-OHL-W-2.0`) | Images extracted unchanged from the public V2.0 assembly DOCX for the GitHub-readable assembly guide. |
| `docs/hardware/v2/YareLampGo_V2.0_assembly_manual.docx` | CERN Open Hardware Licence Version 2 - Weakly Reciprocal (`CERN-OHL-W-2.0`) | Illustrated V2.0 assembly and BOM-reference document. |

License URL: <https://opensource.org/license/CERN-OHL-W-2.0>

## Reserved Rights And Scope

- YareLampGo names, logos, and other brand identifiers are not licensed for
  trademark use except where required for attribution, compatibility description,
  or other legally permitted uses.
- Supplier production drawings, vendor quotations, tooling documents, and private
  manufacturing process materials are not included unless a file is explicitly
  published and listed here or in a local license notice.
- If a future asset needs a different license, add a local notice next to that
  asset and update this file.

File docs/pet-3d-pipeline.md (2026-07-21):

# YareLampGo Pet 3D Pipeline

This document records the v1 asset workflow for the Web pet. The pet is a visual
companion for YareLampGo motion state; it is not a promise of exact physical
kinematic equivalence.

## Source Assets

The public repository keeps the runtime visualization asset used by the Web pet
and the separately approved community printable appearance/structure package.
Production CAD, supplier drawings, STEP/SLDASM/SLDPRT files, and other
manufacturing sources stay outside the public repository unless separately
approved for release. The approved public V2.0 STEP assembly lives under
`assets/printable/YareLampGo_V2.0/`.

Current public Web runtime source:

- `assets/lampgoGLB.glb`
- Served as `/assets/pet/lampgoGLB.glb`
- Licensed as a runtime visualization asset in `ASSET_LICENSES.md`
- Uses `KHR_draco_mesh_compression`, so the browser loader must configure a
  Draco decoder.

## Conversion Workflow

1. Start from an approved visualization source, not from production CAD unless
   that CAD has been cleared for public release.
2. Export a mesh format that Blender can edit reliably, or export GLB directly
   when the hierarchy is preserved and safe to publish.
3. In Blender or in the Web soft-rig layer, clean/map the model:
   - remove internal/invisible details that do not affect the pet silhouette;
   - merge tiny static fasteners into their parent link;
   - keep moving links separated by joint;
   - set each moving link origin at its intended joint pivot;
   - simplify materials for Web rendering.
4. Serve the chosen GLB from repo-level `assets/` via the Web gateway.
5. Update `lampgo/web/static/assets/pet/rig.json` so each YareLampGo joint points to
   either a real GLB node or a virtual Three.js link group.

## Runtime Contract

The Web pet reads joint state only:

- hardware mode: reads live `motion.current_state`;
- `--no-hw` mode: reads `VirtualMotionRuntime.current_state`.

The pet must not send motion commands to the physical robot in v1. Dragging or
posing the pet to control hardware is explicitly out of scope.

## Joint Mapping

The runtime joint names are fixed:

- `base_yaw`
- `base_pitch`
- `elbow_pitch`
- `wrist_roll`
- `wrist_pitch`

`rig.json` maps these names to virtual Three.js link groups. Those groups are
created at load time and matching mesh nodes are attached to them. This is a
soft rig for rigid mechanical links, not a skeleton/skin rig.

## Current GLB Status

`assets/lampgoGLB.glb` is the current runtime model for Web visualization. It is
not the preferred printable model, supplier production drawing, or manufacturing
source.

The file does not contain GLB animation clips, skeletons, or a CAD mate solver.
That is acceptable for YareLampGo v1 because the Web pet already receives five
joint angles from `pet_pose`. The Web layer builds virtual rigid-link groups and
drives those groups directly, similar in spirit to the 2D pet from commit
`81c25a6`.

If the public visualization model is replaced, keep the same runtime contract:
it should be safe to serve in the open repository and should not expose
restricted supplier production details.

## Blender And FreeCAD

Blender is not a YareLampGo runtime dependency. Users do not need it to run
`lampgo`.

Blender is strongly recommended for development because it is the practical
place to inspect model hierarchy, fix pivots, reduce geometry, tune materials,
and export GLB. Blender alone is not enough for SolidWorks files; use FreeCAD,
OpenCascade, SolidWorks export, or a designer-provided GLB/FBX to bridge CAD
into Blender.

## Acceptance Checks

- `uv run lampgo run --web --no-hw` starts with virtual motion running.
- Invoking `nod`, `dance`, or `play_recording` changes pet pose without HAL
  writes.
- Hardware mode continues to use the existing `MotionRuntime + HAL` path.
- If `lampgoGLB.glb` is absent or Draco decoding fails, the generated fallback
  pet still animates.
- If Three.js cannot load, the 2D canvas fallback still animates.

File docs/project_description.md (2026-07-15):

# 项目说明

YareLampGo 想解决一个很朴素的问题：机械臂和具身智能很好玩，但普通人太难上手了。

过去一台 5 自由度机械臂更像实验室里的设备。它能动，但你得懂电机、串口、校准、安全限位、动作规划和一堆底层细节，才能让它做出一个看起来还不错的动作。对普通软件开发者、自媒体创作者和玩家来说，这个门槛太高。

YareLampGo 把这些底层能力打包成一个本地运行时，让机械臂台灯变成更容易使用的桌面小伙伴：它可以听你说话，看见环境，自己动起来，用灯光、动作和语音回应你。

仓库内的 `lampgo` 仍作为内部简称、CLI 命令、Python 包名和配置目录使用。

## 我们最看重的用户价值

- **降低使用门槛**：用户不用先成为机器人专家，就能通过网页、命令行、自然语言或 Agent 控制机械臂。
- **降低创作门槛**：普通开发者可以像调用软件 API 一样调用电机、LED、摄像头和语音能力。
- **降低内容门槛**：创作者可以录制动作、播放表情、设计互动，让桌面硬件更适合短视频、直播和 Demo。
- **降低实验门槛**：硬件团队可以更快验证“有身体的 AI”在桌面场景里到底能做什么。

## 它不是只会聊天的 AI

YareLampGo 的重点不是再做一个聊天框，而是让 AI 能产生真实的身体反馈：

- 用户说“点个头”，台灯真的点头。
- 用户说“做个害羞的表情”，它可以配合动作和 LED 表情回应。
- 用户录制一个动作，下次可以用自然语言、Web UI 或 Agent 再次触发。
- Agent 可以读取摄像头画面，判断桌面环境，再调用动作和表情工具。

## 它把哪些能力接在一起

| 能力 | 对用户意味着什么 |
| --- | --- |
| 运动控制 | 机械臂能安全、平滑地动起来。 |
| 动作录制 | 普通人可以用手摆出动作，保存后反复播放。 |
| LED 表情 | 台灯不只会动，还能用灯光表达状态和情绪。 |
| 摄像头 | 台灯可以看到桌面或用户所在环境。 |
| 语音 | 用户可以说话，台灯也可以语音回应。 |
| 触摸反馈 | 台灯头部触摸电容可以把摸头、轻拍等接触反馈传回 PC，让交互更像真实陪伴。 |
| Web UI | 不写代码也能操作、录制、配置和调试。 |
| Codex 集成 | 复杂任务可以交给用户本机 Codex 规划和执行。 |

## 适合探索的场景

- 桌面陪伴机器人
- 短视频和直播互动道具
- 会动的 AI 助手
- 智能硬件原型 Demo
- Agent 控制真实世界设备
- 面向普通开发者的具身智能创作平台

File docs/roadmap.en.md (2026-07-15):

# Roadmap

This is not a promised schedule. It is a public draft of directions we want to try, and places where outside contributors can help.

## Replaceable Head Modules

YareLampGo starts as a lamp, but we do not want the head to stay locked to only one shape. A better future version could use magnetic or snap-on modules, so the head is easy to swap and easier for the community to modify.

Possible directions:

- Lamp head: lighting, fill light, and expressive LEDs.
- Phone holder: a moving desktop filming stand.
- Small speaker: voice feedback and motion in one desktop device.
- Airflow module: this needs extra power, thermal, and safety design before it should be treated as practical.

## Algorithm Extensions

The repo does not ship VLA, RL, or a large training stack today. The first goal is to make the hardware, motion runtime, safety boundary, Web control, and Agent interface usable.

That said, algorithm contributions are welcome:

- Data collection and motion datasets.
- Imitation learning, policy learning, and RL.
- VLA / vision-language-action models.
- Better perception, tracking, and desktop scene understanding.

The best starting point is to plug into the existing motion system, skill layer, Web API, or Codex MCP interface.

## Desktop Scenarios

We would love to see more everyday use cases:

- Desktop filming assistant.
- Reaction prop for livestreams or videos.
- Motion driven by music or voice mood.
- Agent-controlled hardware with user confirmation.
- User-made motions and skill scenes.

The project should stay easy to run, easy to remix, and easy to reproduce. Serious work can grow from there.

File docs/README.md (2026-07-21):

# YareLampGo 文档中心

简体中文 | [English](README.en.md)

这里整理面向开源用户的中文文档。YareLampGo 想做的事很直接：把机械臂台灯从“实验室硬件”变成普通人也能玩起来的桌面小伙伴，让软件开发者、创作者和玩家都能更容易做出会听、会看、会动、会表达的桌面互动。

对外项目名称使用 **YareLampGo**；文档中的 `lampgo` 是内部简称、CLI 命令、包名或配置目录。

根目录 `README.md` / `README.en.md` 负责快速说明项目价值和启动方式；更长的安装、配置、动作、Codex 和开发说明放在 `docs/` 下维护。

## 入门

| 文档 | 适合场景 |
| --- | --- |
| [快速上手](getting-started/quick-start.md) | 第一次安装、运行 Web UI、验证无硬件模式或连接真实台灯。 |
| [V2.0 手动安装](getting-started/manual-hardware-setup.md) | 不使用 Codex 时，手动完成舵机编号、S3/C6 烧录、首次上电和校准。 |
| [配置说明](getting-started/configuration.md) | 理解 `~/.lampgo/config.toml`、环境变量、凭证和常见配置项。 |

## 使用指南

| 文档 | 适合场景 |
| --- | --- |
| [动作与表情](guides/motion-and-expression.md) | 调用内置动作、录制回放 CSV、控制 LED 表情、制作组合技能。 |
| [Codex 集成](guides/codex-integration.md) | 零配置连接本机 Codex，让复杂任务与台灯工具互通。 |
| [V2.0 硬件与组装](hardware/v2/README.md) | 查看 V2.0 电路/PCB 图、组装说明、接线表、STEP 和首次上电流程。 |

## 架构与背景

| 文档 | 适合场景 |
| --- | --- |
| [系统架构](architecture.md) | 理解 IntentRouter、SkillExecutor、MotionRuntime、SafetyKernel 和 HAL 分层。 |
| [项目说明](project_description.md) | 阅读更完整的项目背景、能力边界和技术路线。 |
| [未来方向](roadmap.md) | 了解可替换头部组件、算法扩展和后续社区共创方向。 |
| [组合技能](composed_skills.md) | 查看用户技能/组合技能的数据结构和执行规则。 |
| [硬件与资产开源范围](hardware-and-assets-scope.md) | 明确软件、固件、3D 可视化资产、社区打印件和供应商生产资料的许可证边界。 |
| [结构件文件](../assets/printable/README.md) | 查看 V2.0 STEP AP214 完整总成、预览和制造边界。 |

## 示例与参考

| 路径 | 内容 |
| --- | --- |
| [`examples/basic_motion.py`](../examples/basic_motion.py) | 基础运动控制示例。 |
| [`examples/custom_skill.py`](../examples/custom_skill.py) | 自定义技能示例。 |
| [`lampgo/mcp_stdio.py`](../lampgo/mcp_stdio.py) | Codex 调用台灯能力的本地 MCP 入口。 |

## 双语维护

- 默认 `README.md` 使用中文。
- 英文入口使用同目录的 `README.en.md`。
- 关键上手文档优先逐步补齐双语；更深的架构、硬件边界和开发记录可以先单语维护。
- 修改双语文档时，请在 PR 中说明另一语言是否已同步；如果暂未同步，明确标记为待补。
- 内部材料、商业 briefing、未公开规划、私有 token、内部服务地址和未授权素材不要从公开文档链接。

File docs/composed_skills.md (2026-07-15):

# 组合技能（ComposedSkill）

YareLampGo 的技能分成三类，彼此来源和可操作性不同：

| 类别 | 存储位置 | 创建方式 | 可编辑 / 删除？ | 在 Web UI 上的位置 |
|---|---|---|---|---|
| **出厂技能** | Python 代码 `lampgo/skills/builtin/` | 仓库内置 | ❌ | 「技能 → 出厂技能」板块 |
| **我的技能** | `~/.lampgo/skills/user/<skill_id>.json` | Codex / Web UI 运行时创建 | ✅ | 「技能 → 我的技能」板块 |
| **录制动作** | `~/.lampgo/recordings/user/<name>.csv` | 手动示教录制 | ✅ | 「录制动作」板块 |

这篇文档讲的是中间一层——**组合技能**，也就是 UI 里「我的技能」对应的那种。

---

## 什么是组合技能？

组合技能是一段 JSON 定义，内容是**按顺序执行若干步骤**。每一步可以是两种形态之一：

- **Level 1 —— 调用出厂技能**：`{"skill_id": "nod", "params": {...}}`
- **Level 2 —— 自定义关节轨迹**：`{"trajectory": {"waypoints": [...], "fps": N, "interpolation": "..."}}`

两种可以**混用**。比如「欢迎回家」= `set_expression(smiley)` → `nod × 2` → 一段自定义 yaw/pitch 摆动轨迹 → `play_recording('wave')`。

你不用写 Python、不用重启守护进程，文件落到 `~/.lampgo/skills/user/` 就会被自动识别并注册成一个正式的 skill，
立刻就能被本地 LLM、Codex、Web UI 的卡片点击等所有入口调用。

## 什么时候用 Level 2（自定义轨迹）？

**优先用 Level 1**。出厂技能（`nod` / `headshake` / `look_at` / `dance` / `idle_sway` / …）里的速度、缓动都是调校过的，能用现成的就别自己造轨迹。

只有在出厂技能**无法表达**你要的动作形态时，才上 Level 2：
- 需要多个关节同时以特定相位联动（出厂里没对应的）
- 需要一个"停留 + 微抖动"之类的非标节奏
- 需要把 yaw、pitch、wrist_roll 按某种特殊顺序编排

## 谁会创建这种技能？

主要是 **Codex**：当用户说「帮我攒一个 XX 技能」，Codex 会先调 `lampgo_list_skills` 看清楚有哪些出厂原子能力，
再通过 LampGo API 或项目文件生成组合方案。
高级用户也可以直接手写 JSON 丢进目录，点一下 Web UI 的「重新加载」就生效。

## JSON 结构

完整示例（`~/.lampgo/skills/user/welcome_home.json`）：

```json
{
  "skill_id": "welcome_home",
  "label": "欢迎回家",
  "description": "当主人到家时执行一段欢迎动作：先抬头看人，切换笑脸，再点头两下。",
  "parameters": {
    "mood": {
      "type": "str",
      "required": false,
      "default": "smiley",
      "description": "使用的 LED 表情名。"
    }
  },
  "steps": [
    { "skill_id": "look_at", "params": { "yaw": 0, "pitch": -20 } },
    { "skill_id": "set_expression", "params": { "expression": "{mood}" } },
    { "skill_id": "nod", "params": { "count": 2, "amplitude": 10 } }
  ]
}
```

### 字段说明

- `skill_id`（必填）：小写字母开头的 `[a-z][a-z0-9_]{0,63}`；不能和出厂技能重名。
- `label`（可选）：Web UI 上显示的中文名；留空会退到 `skill_id`。
- `description`（必填）：一句话描述，会作为工具描述喂给 LLM。
- `parameters`（可选）：对外暴露的参数，和出厂技能的 `ParameterSpec` 格式一致。
- `steps`（必填，非空）：有序步骤列表，上限 20 步。每一步**必须且只能**是以下两种形态之一：
  - **Level 1 调用出厂技能**：
    - `skill_id`：必须是出厂技能 id（`move_to / return_safe / nod / headshake / look_at / idle_sway / dance / set_expression / play_recording` —— `estop` 禁止出现）。
    - `params`（可选）：传给子技能的参数。字符串值可以用 `{外层参数名}` 做替换。
  - **Level 2 自定义轨迹**：
    - `trajectory.waypoints`（必填，≥ 2 个 & ≤ 50 个）：有序关键帧。每一帧：
      - `joints`（必填）：目标关节角（度），键限定在 `base_yaw / base_pitch / elbow_pitch / wrist_roll / wrist_pitch`。
        未指定的关节**保持上一帧的值**；第一帧中未指定的关节会填入**机器人当前实时姿态**——这样轨迹开头不会出现"瞬跳"。
      - `duration`（可选，秒，≥ 0）：从上一关键帧运动到本关键帧的时长。第一帧的 `duration` 会被忽略（它就是起点）。
    - `fps`（可选，默认 50，范围 [10, 100]）：帧流速率。
    - `interpolation`（可选，默认 `ease_in_out_cubic`）：缓动函数，白名单是 `linear / ease_in_out_cubic / ease_in_out_quad / ease_out_cubic / ease_in_cubic / ease_out_back`。
    - `ease_overshoot`（可选，默认 0.10，范围 [0.0, 0.5]）：仅对 `ease_out_back` 生效。

## 安全护栏

服务端在加载和保存时统一做校验（`lampgo/skills/loader.py`），下面这些会直接被拒：

**通用**
- `skill_id` 格式不对 / 和出厂技能重名；
- `steps` 为空、> 20 步；
- 一个步骤**同时**带 `skill_id` 和 `trajectory`（必须二选一）；
- 步骤里出现 `estop`（安全关机不是可组合的原语）。

**Level 1（`skill_id` 步骤）**
- 引用了未注册的 skill；
- 引用另一个组合技能（禁止组合套组合，杜绝递归）。

**Level 2（`trajectory` 步骤）**
- `waypoints` < 2 或 > 50；
- 关节名不在白名单；
- 关节角度超出硬件限幅（`DEFAULT_JOINT_LIMITS`，如 `base_yaw ∈ [-150, 150]`）；
- `fps` 不在 [10, 100]；
- `interpolation` 不在白名单；
- 总 `duration` > 30 秒。

> 注意：**单段速度超限不会被拒绝**。`generate_waypoint_frames` 会自动把该段拉长到安全范围，
> 对人类来说比"报错让你重填"体验更好。但如果你写了一个 0.01 s 要走 90° 的段，它实际会被延长到 ~0.5 s。

## 运行时行为

- 组合技能不走 `SkillExecutor` 去调用子步骤——会自我取消。它直接调 `child.execute(ctx, **step_params)`。
- 轨迹步骤在每次执行时**当场生成帧**，不是在保存时预生成——这样 `SafetyConfig.max_velocity` 的动态调整能立即生效。
- 任何一步返回 `error`，整个技能以 `step <i> (...): <message>` 的形式上抛错误。
- 外层 executor cancel / preempt 时：
  - 如果当前跑的是出厂技能步骤，会 `cancel()` 该子技能；
  - 如果当前跑的是轨迹步骤，会 `motion.stop_immediate()` 让舵机总线当场停下。

## 与 LLM agent 的关系

保存或删除一个组合技能后，服务端会立即重建 LLM 的工具列表
（`Server._refresh_llm_skill_tools`），
下一个回合 LLM 就能把这个技能当作普通 tool 调用，无需重启。

## 相关文件

- `lampgo/skills/composed.py` — ComposedSkill 类
- `lampgo/skills/loader.py` — JSON 校验 / 落盘 / 扫描
- `lampgo/skills/registry.py` — 新增 `unregister()`，只允许移除 user 级技能
- `lampgo/web/gateway.py` — `/api/skills/save`、`/api/skills/delete`、`/api/skills/reload`
- `lampgo/mcp_stdio.py` — Codex 可用的 LampGo MCP 工具入口
- `tests/test_user_skill_loader.py` + `tests/test_composed_skill.py` — 回归测试

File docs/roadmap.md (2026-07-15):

# 未来方向

这里不是排期承诺，更像一张公开草稿：我们把现在想做、也希望社区一起试的方向放在这里。做出来之前，它都只是方向。

## 可替换头部

YareLampGo 现在首先是台灯，但我们不想把它锁死在“灯”这个形态里。后续更理想的结构是磁吸或卡扣式头部组件，换起来简单，也方便社区自己做小模块。

可能的头部方向：

- 灯头：照明、补光、表情灯。
- 手机支架：把机械臂变成会动的桌面拍摄支架。
- 小音箱：让语音反馈和动作放在同一个桌面设备上。
- 吹风或气流模块：这类会涉及功率、温控和安全保护，只适合在额外安全设计完成后再尝试。

## 算法扩展

这个仓库现在没有内置 VLA、RL 或大规模训练流程。我们先把硬件、动作、安全边界、Web 控制和 Agent 接口打通，让设备能被普通开发者跑起来。

但这不代表我们不关心算法。相反，我们希望以后有人把这些方向接进来：

- 数据采集和动作数据集整理。
- 模仿学习、策略学习和 RL。
- VLA / 视觉语言动作模型。
- 更好的视觉感知、目标跟踪和桌面场景理解。

如果你想贡献这类能力，最好的切入点是接入现有的动作、技能、Web API 或 Codex MCP 接口。

## 桌面场景

我们很期待看到更生活化的玩法，比如：

- 桌面拍摄助手。
- 直播或视频里的反应道具。
- 跟随音乐或语音情绪做动作。
- 带确认机制的 Agent 硬件执行器。
- 适合普通用户自己组合的动作和 skill 场景。

小项目先好玩、好改、好复现，才有机会长出更严肃的东西。

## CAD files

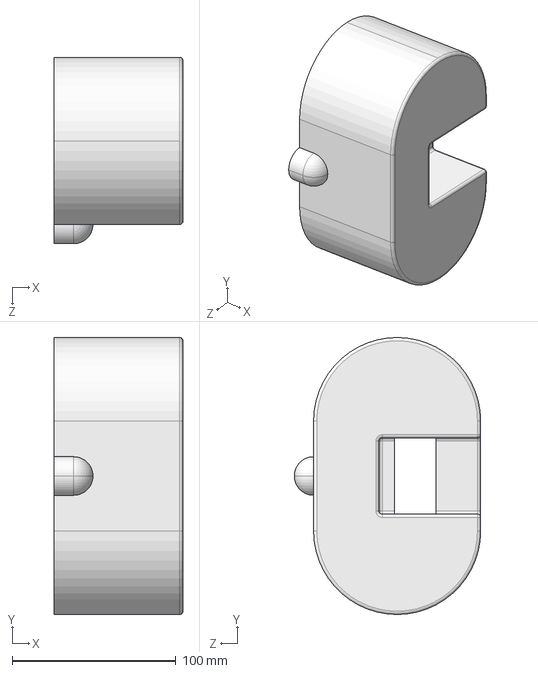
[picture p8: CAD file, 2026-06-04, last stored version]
assets/printable/YareLampGo_V1.0/灯头.STEP
78.7 x 169.0 x 113.8 mm

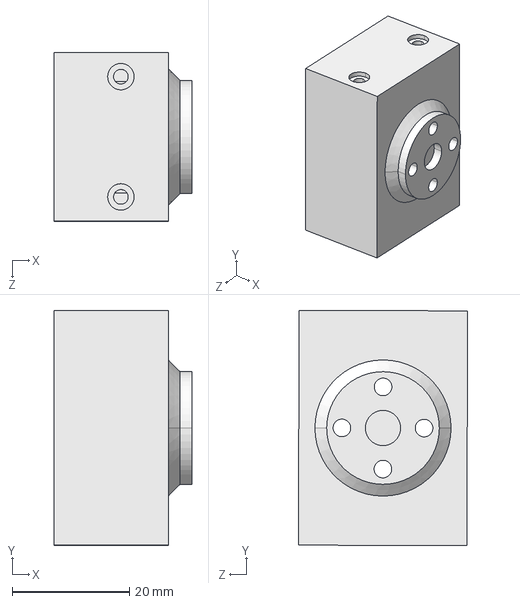
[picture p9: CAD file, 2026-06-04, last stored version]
assets/printable/YareLampGo_V1.0/卡口2.STEP
23.5 x 40.1 x 28.8 mm

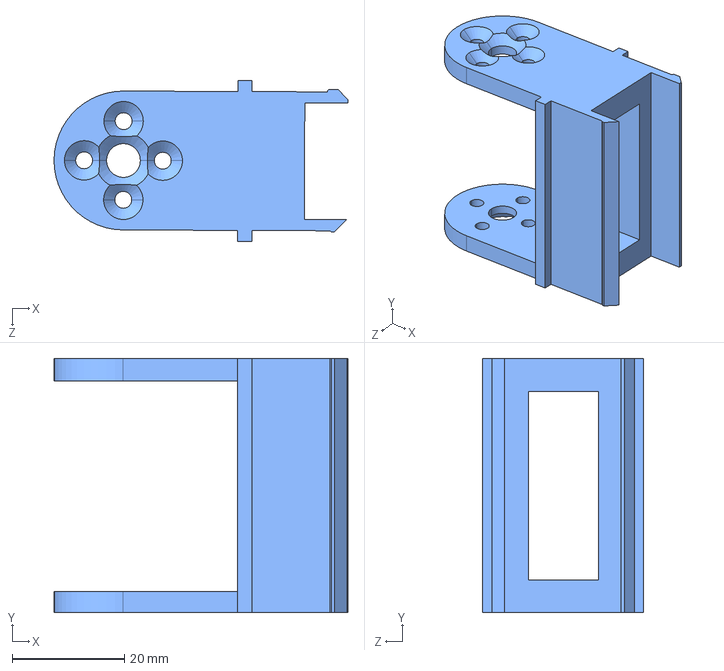
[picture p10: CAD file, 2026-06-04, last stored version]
assets/printable/YareLampGo_V1.0/卡口1.STEP
52.3 x 45.3 x 28.7 mm

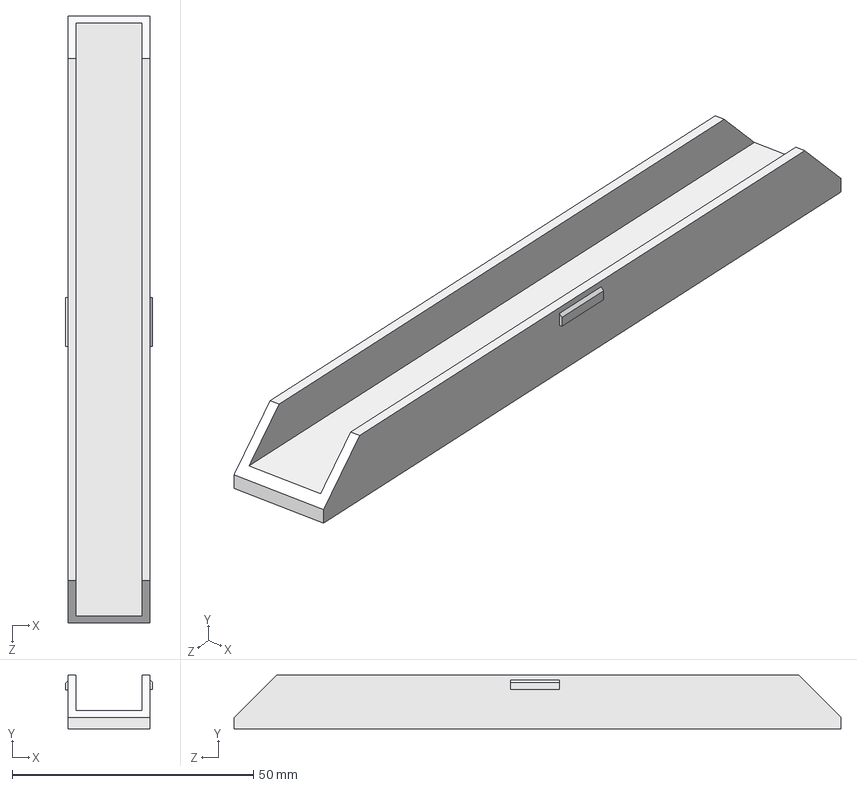
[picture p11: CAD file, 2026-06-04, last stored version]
assets/printable/YareLampGo_V1.0/盖板.STEP
18.0 x 11.2 x 125.8 mm

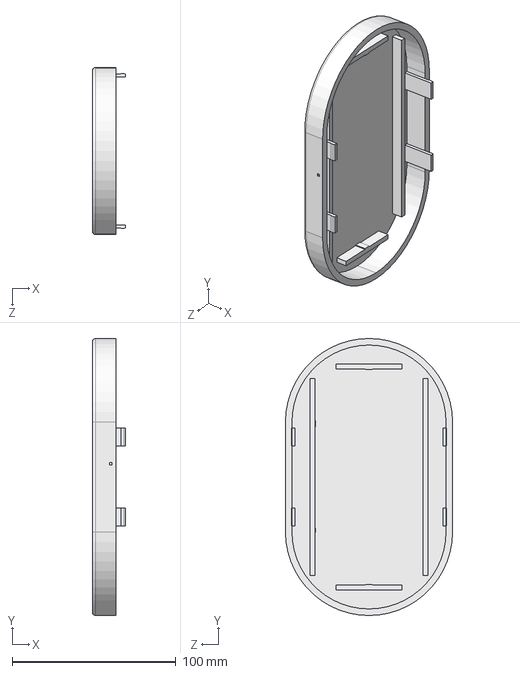
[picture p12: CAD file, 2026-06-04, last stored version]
assets/printable/YareLampGo_V1.0/灯罩.STEP
20.4 x 169.0 x 102.0 mm

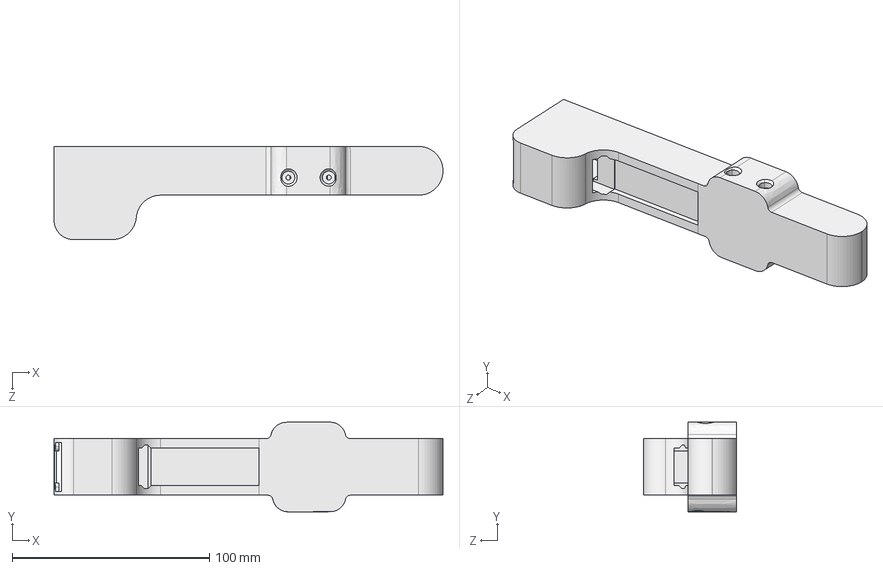
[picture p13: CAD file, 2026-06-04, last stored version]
assets/printable/YareLampGo_V1.0/连杆1.STEP
197.3 x 45.5 x 47.2 mm

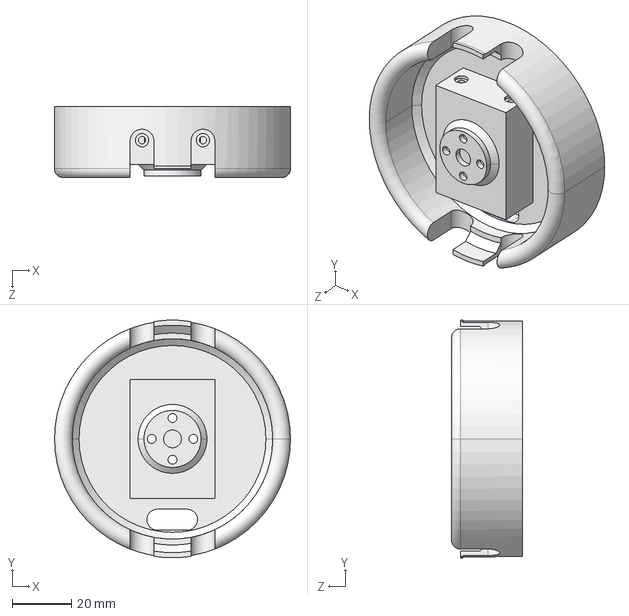
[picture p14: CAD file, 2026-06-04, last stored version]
assets/printable/YareLampGo_V1.0/底座盖板.STEP
79.4 x 79.9 x 24.0 mm

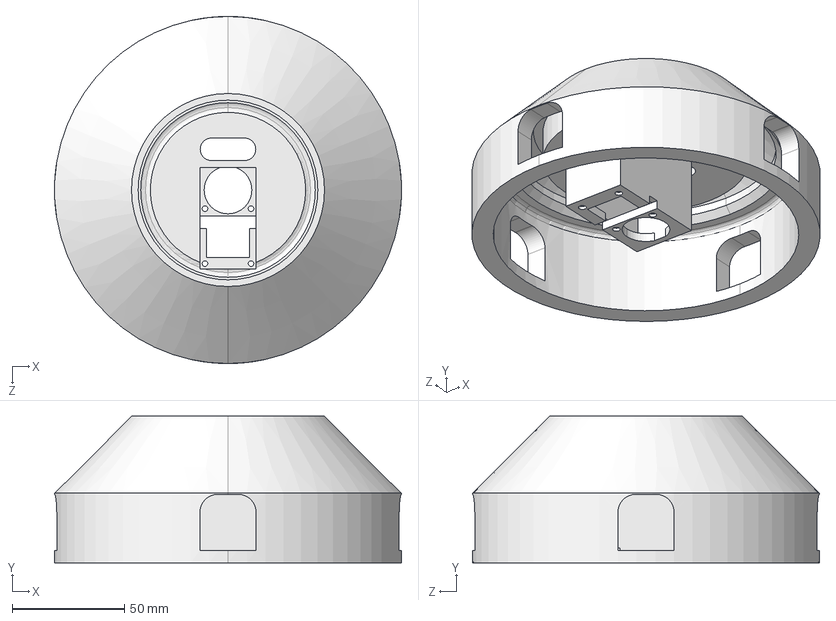
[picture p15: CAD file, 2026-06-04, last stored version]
assets/printable/YareLampGo_V1.0/底座.STEP
154.5 x 65.3 x 154.5 mm

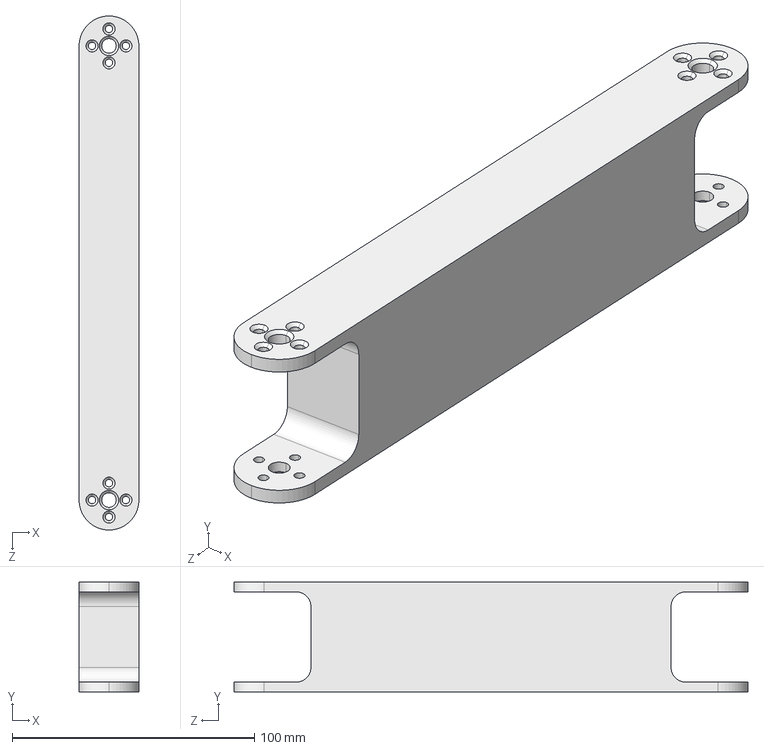
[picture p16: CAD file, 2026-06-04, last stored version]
assets/printable/YareLampGo_V1.0/连杆2.STEP
24.7 x 45.3 x 212.4 mm

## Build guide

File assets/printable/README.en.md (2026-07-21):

# YareLampGo V2.0 Structure

[简体中文](README.md) | English

V2.0 is the only currently maintained public hardware structure. The V1.0 package has been removed from the main line; do not mix V1.0 and V2.0 bases, arms, motor shells, or head parts.

YareLampGo V2.0 assembly preview

## Download The Complete STEP Assembly

[**Download the complete YareLampGo V2.0 STEP assembly (73 MB)**](YareLampGo_V2.0/YareLampGo_V2.0_assembly.step)

This is a complete assembly for CAD tools such as SolidWorks, Fusion 360, and FreeCAD—not a per-part STL/3MF printing package.

## Files

| File | Purpose |
| --- | --- |
| [YareLampGo_V2.0_assembly.step](YareLampGo_V2.0/YareLampGo_V2.0_assembly.step) | Complete STEP AP214 assembly exported by SolidWorks 2022, in millimetres. |
| `YareLampGo_V2.0/assembly-preview.png` | Assembly preview extracted from the official guide. |
| [GitHub-readable assembly guide (Chinese)](../../docs/hardware/v2/YareLampGo_V2.0_assembly_manual.md) | Browse the illustrated BOM, fastener, cable-routing, and assembly guide. |
| [Original assembly DOCX](../../docs/hardware/v2/YareLampGo_V2.0_assembly_manual.docx) | Download the original guide for offline viewing or printing. |
| [`../../docs/hardware/v2/README.en.md`](../../docs/hardware/v2/README.en.md) | Searchable V2.0 assembly, electrical, and first-power guide. |

## Boundaries

- The STEP file is a complete assembly, not a print-ready per-part STL/3MF package. Export printable bodies or parts in CAD and verify units, tolerances, wall thickness, insert holes, and print orientation.
- Purchased components such as the S3, C6, PCB, LED board, and servos are included as reference geometry. Exclude them when exporting structural parts.
- Recalibrate after the first assembly or any structural change. Do not reuse V1.0 or another unit's calibration data.
- Source names, checksums, and publication limits are recorded in [`../../docs/hardware/v2/SOURCE_MANIFEST.md`](../../docs/hardware/v2/SOURCE_MANIFEST.md).

## License

Unless a local notice says otherwise, the public STEP and preview image use `CERN-OHL-W-2.0`. See [ASSET_LICENSES.md](../../ASSET_LICENSES.md).

This package is not a production-approved supplier drawing set. Verify dimensions, tolerances, materials, loads, cable movement, and electrical safety before fabrication.

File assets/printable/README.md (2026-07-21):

# YareLampGo V2.0 结构件

简体中文 | [English](README.en.md)

V2.0 是当前唯一维护的公开硬件结构版本。V1.0 结构件已从主线移除；两个版本的底座、支撑杆、电机外壳和灯头不应混装。

YareLampGo V2.0 装配预览

## 下载完整 STEP 总成

[**下载 YareLampGo V2.0 完整 STEP 总成（73 MB）**](YareLampGo_V2.0/YareLampGo_V2.0_assembly.step)

这是可在 SolidWorks、Fusion 360、FreeCAD 等 CAD 软件中打开的完整装配文件，不是逐件 STL/3MF 打印包。

## 文件

| 文件 | 说明 |
| --- | --- |
| [YareLampGo_V2.0_assembly.step](YareLampGo_V2.0/YareLampGo_V2.0_assembly.step) | SolidWorks 2022 导出的 STEP AP214 完整总成，单位为毫米。 |
| `YareLampGo_V2.0/assembly-preview.png` | 从官方组装说明中提取的总成预览。 |
| [GitHub 网页版组装说明](../../docs/hardware/v2/YareLampGo_V2.0_assembly_manual.md) | 直接查看物料图片、紧固件位置、走线和装配顺序。 |
| [原始组装 DOCX](../../docs/hardware/v2/YareLampGo_V2.0_assembly_manual.docx) | 可下载、离线查看或打印的原始图文说明。 |
| [`../../docs/hardware/v2/README.md`](../../docs/hardware/v2/README.md) | 可搜索的 V2.0 组装、电路和首次上电说明。 |

## 使用边界

- STEP 是完整装配总成，不是已经按 3D 打印流程拆好的逐件 STL/3MF 包。请在 CAD 中按实体/零件导出，并自行确认单位、公差、壁厚、螺纹嵌件孔和打印方向。
- 总成包含结构件以及 S3、C6、PCB、LED、舵机等参考模型。制造结构件前应隐藏或排除采购件。
- 首次安装或更换结构件后必须重新校准。不要复用另一台设备或 V1.0 的校准数据。
- V2.0 原始文件、校验和与能力边界见 [`../../docs/hardware/v2/SOURCE_MANIFEST.md`](../../docs/hardware/v2/SOURCE_MANIFEST.md)。

## 许可

除非本地文件另有说明，本目录中的公开 STEP 和预览图按 `CERN-OHL-W-2.0` 发布。仓库级资产授权表见 [ASSET_LICENSES.md](../../ASSET_LICENSES.md)。

本文件包不是经过量产签核的供应商图纸集。打印或加工前，请自行完成尺寸、公差、材料、载荷、线束活动空间和电气安全复核。

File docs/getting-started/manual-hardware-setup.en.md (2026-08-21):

# Manual YareLampGo V2.0 Setup, Flashing, and First Start

This guide covers the complete non-Codex path: install the software, assign five servo IDs, flash the S3 and C6, assemble while unpowered, verify power, calibrate, and start the Web console.

Codex users can use the repository's [`$lampgo-setup`](../../skills/lampgo-setup/SKILL.md) instead. It follows the same sequence, inspects the actual environment, performs safe steps, and pauses before hardware writes and first power.

## 0. Confirm the version and safety boundary

- This guide is for **YareLampGo V2.0** only. Do not mix V1 structures, wiring, or calibration files.
- Remove 12V before writing a servo ID or changing motor wiring. Only one servo may be on the bus during ID assignment.
- On a new board, remove the S3, C6, LED, and amplifier before checking that the logic rail is really +5V.
- Do not combine USB power and external +5V unless the hardware's backfeed protection has been verified.
- Support the mechanism, clear its motion envelope, and be ready to stop or remove 12V during calibration and first motion.

Keep these references open:

- [V2.0 Hardware and Assembly](../hardware/v2/README.en.md)
- [V2.0 Wiring Guide](../hardware/wiring.md)
- [GitHub-readable illustrated assembly guide (Chinese)](../hardware/v2/YareLampGo_V2.0_assembly_manual.md)
- [Original illustrated assembly DOCX download](../hardware/v2/YareLampGo_V2.0_assembly_manual.docx)

## 1. Install LampGo

Clone the repository:

```bash
git clone https://github.com/ninsmiracle/YareLampGo.git
cd YareLampGo
```

macOS / Linux:

```bash
./install.sh
```

Windows PowerShell:

```powershell
powershell -ExecutionPolicy Bypass -File .\install.ps1
```

The installer prepares the verified `uv` version, Python 3.12, and locked dependencies. Verify the CLI:

```bash
uv --version
uv run python --version
uv run lampgo help
```

For a software-only trial, skip the remaining hardware steps:

```bash
uv run lampgo onboard
uv run lampgo run --web --no-hw
```

## 2. Assign the five servo IDs

Assign IDs before mechanical assembly:

| Position | Program name | ID |
| --- | --- | ---: |
| Base rotation | `base_yaw` | 1 |
| Base pitch | `base_pitch` | 2 |
| Elbow pitch | `elbow_pitch` | 3 |
| Wrist roll | `wrist_roll` | 4 |
| Wrist pitch | `wrist_pitch` | 5 |

Discover the serial port, then start one complete assignment session. On Windows, `setup-motors` probes COM ports automatically; use `--auto-detect` (or `--rescan`) to ignore a stale saved port and force a fresh scan. If several ports remain ambiguous, choose the numbered candidate or specify `--port` explicitly.

```bash
uv run lampgo detect
uv run lampgo setup-motors
```

Specify the port when detection is ambiguous:

```bash
uv run lampgo setup-motors --port /dev/tty.usbmodemXXXX
```

Windows PowerShell uses the actual `COM` port:

```powershell
uv run lampgo setup-motors --port COM5
```

At every prompt, remove 12V, connect only the servo for the named position, then restore power. Do not restart the five-servo wizard separately for every motor.

Connect the full chain and require one stable response from each ID:

```bash
uv run lampgo scan-motors --auto-detect --ids 1-5
uv run lampgo ping --auto-detect
```

Resolve missing, duplicate, or intermittent IDs before calibration.

## 3. Flash the S3 camera/audio controller

Firmware is maintained in a separate repository. Use that repository's current README and scripts as the source of truth:

```bash
git clone https://github.com/shelly-tang/YareLampGo_esp32.git
cd YareLampGo_esp32
./scripts/flash.sh --list-ports
```

With Arduino IDE or `arduino-cli` installed, build and flash from source:

```bash
./scripts/flash.sh --port /dev/cu.usbmodemXXXX --erase --monitor
```

Without Arduino, use the included prebuilt package:

```bash
cd dist/YareLampGo_esp32-firmware
./flash.sh --prebuilt . --port /dev/cu.usbmodemXXXX --erase --monitor
```

Use `--erase` only for first installation or deliberate recovery. It clears saved Wi-Fi and device pairing. Omit it during normal updates when those settings should remain.

Windows users can flash from Arduino IDE by selecting `XIAO_ESP32S3` with OPI PSRAM. See the [firmware flashing guide](https://github.com/shelly-tang/YareLampGo_esp32) for current dependencies, prebuilt packages, and BOOT/RESET recovery.

A successful upload is not full hardware validation. Continue by checking boot logs, camera, microphone, speaker, LED, Wi-Fi, and the UART link to the C6.

## 4. Flash the C6 eye display

Connect the C6 separately and confirm its port is not the S3 port. From the firmware repository root:

```bash
arduino-cli compile --upload \
  --port /dev/cu.usbmodemYYYY \
  --fqbn esp32:esp32:esp32c6:FlashSize=8M \
  ESP32_C6_LCD_1_47_UART
```

The C6 requires the 8MB partition layout. The first migration from an older layout requires an erase and reflash and removes cached eye clips. See [`ESP32_C6_LCD_1_47_UART/README.md`](https://github.com/shelly-tang/YareLampGo_esp32/blob/main/ESP32_C6_LCD_1_47_UART/README.md) for the current migration notes.

On Windows, use the same command with the actual `COM` port when `arduino-cli` is installed, or select the ESP32-C6 and 8MB Flash in Arduino IDE before compiling and uploading.

## 5. Assemble and inspect while unpowered

Follow [V2.0 Hardware and Assembly](../hardware/v2/README.en.md) and the assembly DOCX with 12V and USB disconnected. Verify:

- Servo cables are not pinched and are not tensioned or abraded through the full joint range.
- S3 GPIO43 TX → C6 RX, and S3 GPIO44 RX ← C6 TX.
- The LED U3 pin order matches PCB markings and measured connector orientation, not wire color alone.
- The 12V motor side and +5V logic side are not swapped, and all logic grounds are common.
- Fasteners, heat-set inserts, and connectors are secure, with no loose metal near the PCB.

The schematic PNG files are wiring and review references, not board-house-ready Gerbers.

## 6. First power

1. Remove the S3, C6, LED, and amplifier, then apply 12V only to the power module.
2. Measure +5V relative to GND. Remove power immediately if polarity or voltage is wrong.
3. Power down, reinstall the logic modules, and verify the S3 and C6 separately over USB.
4. Keep the joints away from hard stops, clear the motion envelope, and support the mechanism.
5. Apply servo 12V and run read-only checks first:

```bash
cd YareLampGo
uv run lampgo detect
uv run lampgo scan-motors --auto-detect --ids 1-5
uv run lampgo ping --auto-detect
```

Do not calibrate until all five motors are stable and the direction, harness, and power checks have passed.

## 7. Calibrate, provision, and start

Run calibration from the YareLampGo repository root. Inspect `assets/calibration/` first. If the same `lamp_id` already has a file, copy it to a backup outside the repository instead of overwriting or deleting it.

```bash
uv run lampgo calibrate --auto-detect
```

Specify a device when needed:

```bash
uv run lampgo calibrate --port /dev/tty.usbmodemXXXX --id AL02
```

Windows example:

```powershell
uv run lampgo calibrate --port COM5 --id AL02
```

Complete onboarding and start the lamp:

```bash
uv run lampgo onboard
uv run lampgo run --web
```

Open <http://127.0.0.1:8420>. After an S3 erase flash, connect to `Lampgo-Setup-XXXX`, then use Web settings to join the same 2.4GHz Wi-Fi network as the computer.

In another terminal, check the running daemon:

```bash
uv run lampgo status
uv run lampgo skills
```

Use a small, slow movement for the first physical test:

```bash
uv run lampgo move base_yaw=5 --velocity 20
uv run lampgo invoke return_safe
```

Run `uv run lampgo estop` on abnormal motion and remove 12V if necessary. Prefer `Ctrl+C` to stop the daemon; use `uv run lampgo clear` if a process or motor torque remains.

## Command reference

```bash
uv run lampgo help
uv run lampgo <command> --help
```

The root [README](../../README.en.md) also keeps the most-used command list visible.

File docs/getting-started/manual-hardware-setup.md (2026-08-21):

# YareLampGo V2.0 手动安装、烧录与首次启动

本文给不使用 Codex skill 的用户提供完整手动路径：安装软件、给五颗舵机编号、烧录 S3/C6、断电组装、检查供电、校准并启动 Web 控制台。
Windows x64 用户也可以直接按 [Windows 硬件完整流程](windows-hardware-flow.md) 逐步执行。

如果你使用 Codex，可以改用仓库自带的 [`$lampgo-setup`](../../skills/lampgo-setup/SKILL.md)。它执行的仍是同一套流程，只是会读取实际环境、运行安全步骤，并在硬件写入和首次上电前停下来确认。

## 0. 先确认版本和安全边界

- 本文只适用于 **YareLampGo V2.0**，不要混用 V1 结构、接线或校准文件。
- 写舵机 ID 或换舵机线前必须断开 12V；设置 ID 时总线上只能有一颗舵机。
- 新主板先移除 S3、C6、LED 和功放，确认 +5V 输出正确后再安装逻辑模块。
- 未确认防反灌设计前，不要同时使用 USB 和外部 +5V 给同一模块供电。
- 校准和首次运动时扶稳机构、清空运动范围，并准备随时急停或断开 12V。

结构、接线和首次上电检查必须配合阅读：

- [V2.0 硬件与组装](../hardware/v2/README.md)
- [V2.0 接线指南](../hardware/wiring.md)
- [GitHub 网页版图文组装说明](../hardware/v2/YareLampGo_V2.0_assembly_manual.md)
- [原始图文组装 DOCX 下载](../hardware/v2/YareLampGo_V2.0_assembly_manual.docx)

## 1. 安装 LampGo 软件

获取代码：

```bash
git clone https://github.com/ninsmiracle/YareLampGo.git
cd YareLampGo
```

macOS / Linux：

```bash
./install.sh
```

Windows PowerShell：

```powershell
powershell -ExecutionPolicy Bypass -File .\install.ps1
```

安装器会准备已验证的 `uv`、Python 3.12 和锁定依赖。完成后先确认 CLI：

```bash
uv --version
uv run python --version
uv run lampgo help
```

如果你只想体验软件，可以跳过后面的硬件步骤：

```bash
uv run lampgo onboard
uv run lampgo run --web --no-hw
```

## 2. 给五颗舵机编号

组装前按下面的对应关系写入 ID：

| 位置 | 程序名称 | ID |
| --- | --- | ---: |
| 底座水平旋转 | `base_yaw` | 1 |
| 底座俯仰 | `base_pitch` | 2 |
| 肘部俯仰 | `elbow_pitch` | 3 |
| 手腕滚转 | `wrist_roll` | 4 |
| 手腕俯仰 | `wrist_pitch` | 5 |

先运行只读探测。Windows 会扫描 `COM` 口，并尝试识别 Feetech 电机总线：

```bash
uv run lampgo detect
```

再启动一次完整编号向导。省略 `--port` 时，命令先使用配置里已保存的 `device.motor_port`；没有保存端口时才自动探测：

```bash
uv run lampgo setup-motors
```

如果旧配置可能过期，强制忽略已保存的端口并重新扫描：

```bash
uv run lampgo setup-motors --auto-detect
```

如果多个串口无法安全区分，向导会列出候选并要求选择；也可以显式指定：

```bash
uv run lampgo setup-motors --port /dev/tty.usbmodemXXXX
```

Windows PowerShell 使用实际的 `COM` 口：

```powershell
uv run lampgo setup-motors --port COM5
```

每次按向导切换舵机时，都要先断开 12V，只连接当前要编号的一颗舵机，再恢复供电。不要为每颗舵机重新启动五舵机向导。

全部写完后连接完整总线，检查 ID 1～5 是否各有一个稳定响应：

```bash
uv run lampgo scan-motors --auto-detect --ids 1-5
uv run lampgo ping --auto-detect
```

缺失、重复或时有时无都要先排除，不能直接进入校准。

## 3. 烧录 S3 摄像头/音频主控

固件在独立仓库中，烧录前以该仓库的当前说明和脚本为准：

```bash
git clone https://github.com/shelly-tang/YareLampGo_esp32.git
cd YareLampGo_esp32
./scripts/flash.sh --list-ports
```

安装了 Arduino IDE 或 `arduino-cli` 时，可以从源码编译并烧录：

```bash
./scripts/flash.sh --port /dev/cu.usbmodemXXXX --erase --monitor
```

没有 Arduino 时，可使用仓库提供的预编译包：

```bash
cd dist/YareLampGo_esp32-firmware
./flash.sh --prebuilt . --port /dev/cu.usbmodemXXXX --erase --monitor
```

`--erase` 只用于第一次安装或明确的恢复操作，它会清空旧 Wi-Fi 和设备绑定。普通固件升级且需要保留配网信息时去掉 `--erase`。

Windows 用户可使用 Arduino IDE 打开源码并选择 `XIAO_ESP32S3`，同时启用 OPI PSRAM；预编译包、依赖和 BOOT/RESET 故障处理见 [固件仓库中文烧录指南](https://github.com/shelly-tang/YareLampGo_esp32/blob/main/README.zh-CN.md)。

烧录完成不代表整机链路已经通过。至少要继续验证启动日志、摄像头、麦克风、扬声器、LED、Wi-Fi 和与 C6 的 UART 通信。

## 4. 烧录 C6 眼睛屏幕

先单独连接 C6，确认它和 S3 使用的不是同一个串口。进入固件仓库根目录后运行：

```bash
arduino-cli compile --upload \
  --port /dev/cu.usbmodemYYYY \
  --fqbn esp32:esp32:esp32c6:FlashSize=8M \
  ESP32_C6_LCD_1_47_UART
```

C6 必须使用 8MB Flash 分区。旧分区第一次迁移需要擦除后重刷，会删除已经缓存的眼睛动画；具体迁移说明见固件仓库的 [`ESP32_C6_LCD_1_47_UART/README.md`](https://github.com/shelly-tang/YareLampGo_esp32/blob/main/ESP32_C6_LCD_1_47_UART/README.md)。

Windows 上安装了 `arduino-cli` 时使用同一条命令，并把 `--port` 的值换成实际 `COM` 口；也可以在 Arduino IDE 中选择 ESP32-C6 和 8MB Flash 后编译上传。

## 5. 断电组装并检查接线

按 [V2.0 硬件与组装](../hardware/v2/README.md) 和 [GitHub 网页版组装说明](../hardware/v2/YareLampGo_V2.0_assembly_manual.md) 完成机械结构。全程断开 12V 和 USB，重点检查：

- 舵机线没有被外壳夹住，也不会在全行程中被拉扯或磨损。
- S3 GPIO43 TX → C6 RX，S3 GPIO44 RX ← C6 TX。
- LED U3 针序按 PCB 丝印和实测方向连接，不能只看线色。
- 12V 舵机侧与 +5V 逻辑侧没有接反，所有逻辑地共地。
- 紧固件、热熔嵌件和连接器已固定，没有松动金属可能碰到 PCB。

电路 PNG 是接线和审查参考，不是可以直接下单的 Gerber 制板包。

## 6. 首次上电

1. 移除 S3、C6、LED 和功放，只给电源模块接入 12V。
2. 用万用表测量 +5V 对 GND。极性或电压不正确时立即断电。
3. 断电后装回逻辑模块，分别通过 USB 确认 S3 和 C6 能启动。
4. 检查关节远离机械限位、运动范围无人无物，扶稳机构。
5. 再接入舵机 12V，先只运行只读检测：

```bash
cd YareLampGo
uv run lampgo detect
uv run lampgo scan-motors --auto-detect --ids 1-5
uv run lampgo ping --auto-detect
```

只有五颗舵机全部稳定在线，且方向、线束和电源均确认后，才能校准。

## 7. 校准、配网和启动

从 YareLampGo 仓库根目录运行校准。先检查 `assets/calibration/`；如果相同 `lamp_id` 已有文件，先复制到仓库外的备份目录，不要直接覆盖或删除。

```bash
uv run lampgo calibrate --auto-detect
```

需要指定设备时：

```bash
uv run lampgo calibrate --auto-detect --id AL02
```

Windows 示例：

```powershell
uv run lampgo calibrate --port COM5 --id AL02
```

然后完成软件配置并启动：

```bash
uv run lampgo onboard
uv run lampgo run --web
```

浏览器打开 <http://127.0.0.1:8420>。如果 S3 做过擦除烧录，先连接 `Lampgo-Setup-XXXX` 热点，再在 Web 设置中把设备接入与电脑相同的 2.4GHz Wi-Fi。

另开终端确认运行状态：

```bash
uv run lampgo status
uv run lampgo skills
```

第一次真实动作先做小角度、低速度测试，不要直接播放大幅动作：

```bash
uv run lampgo move base_yaw=5 --velocity 20
uv run lampgo invoke return_safe
```

发生异常立即运行 `uv run lampgo estop`，必要时断开 12V。退出 daemon 优先使用 `Ctrl+C`；如果进程或扭矩未释放，再运行 `uv run lampgo clear`。

## 常用命令去哪查

```bash
uv run lampgo help
uv run lampgo <command> --help
```

根目录 [README](../../README.md) 也保留了最常用命令速查。

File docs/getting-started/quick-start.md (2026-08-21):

# 快速上手

本文面向第一次运行 YareLampGo 的用户，目标是在几分钟内启动本地 Web 控制台，并确认软件链路或真实硬件链路可用。命令行入口仍使用 `lampgo`。

## 环境要求

- Python 3.12+
- `uv`（一键安装器会自动准备）
- macOS、Linux 或 Windows
- 可选硬件：兼容的 5-DOF Feetech 机械臂台灯、ESP32 LED 控制器、摄像头、麦克风

Python 由 `uv` 自动管理，通常不需要手工创建虚拟环境。

## 获取代码

```bash
git clone https://github.com/ninsmiracle/YareLampGo.git
cd YareLampGo
```

## Codex 交互式安装（推荐）

Codex 用户可以先安装仓库自带的 `lampgo-setup` skill：

```bash
./install-codex-skill.sh
```

Windows PowerShell：

```powershell
powershell -ExecutionPolicy Bypass -File .\install-codex-skill.ps1
```

新建 Codex 任务后说：`用 $lampgo-setup 帮我安装和配置 YareLampGo V2.0`。skill 会区分纯软件、已组装成品和 DIY V2.0 三条路径，并在硬件写入/上电/校准前逐步确认。手工安装可以继续按下文执行。

如果需要从舵机编号和 S3/C6 烧录开始复刻整机，请直接阅读 [V2.0 手动安装、烧录与首次启动](manual-hardware-setup.md)。Windows x64 用户也可以直接按 [Windows x64 硬件完整流程](windows-hardware-flow.md) 从安装一路执行到首次动作。

## 一键安装全部依赖

macOS / Linux：

```bash
./install.sh
```

Windows PowerShell：

```powershell
powershell -ExecutionPolicy Bypass -File .\install.ps1
```

安装器自动完成平台与 CPU 检查、已验证 `uv` 版本和 Python 3.12 准备、Linux PortAudio/源码构建工具安装、锁定的 Python 依赖同步，以及 LiveKit SDK import/CLI 验证。Python 包全部由 `uv sync --locked` 管理，不会混用系统 `pip`。SDK 使用公网 PyPI 的 `lampgo-livekit-agent-sdk`，不需要连接小米内网。

安装输出会实时显示在终端，同时写入 `~/.lampgo/logs/install-*.log`。失败后请保留终端最后的“失败阶段”和日志文件；修复网络、权限或系统版本问题后直接重跑同一命令即可，`uv` 会复用已下载缓存。

当前完整依赖矩阵：

| 平台 | 安装状态 | 说明 |
| --- | --- | --- |
| macOS 14+ Apple Silicon | 支持 | 包含预编译系统音频组件。 |
| Windows x64 | 支持 | 使用回环 TCP IPC、COM 串口探测和 Windows 进程管理；音乐模式可读取默认录音设备或 Stereo Mix。 |
| 常见 glibc Linux x64 / ARM64 | 支持 | 自动识别 apt、dnf、yum、zypper 或 pacman 安装 PortAudio。 |
| Intel Mac / Windows ARM64 | 暂不支持 | 当前锁定的原生 wheel 不完整，安装器会提前给出明确提示。 |

如果只想先调试 Web、配置和 Agent 链路，可以不连接硬件。

### Windows 注意事项

- PowerShell 中使用 COM5 这类实际串口名，不要填写 Linux 的 /dev/ttyUSB0。
- LampGo 在 Windows 上通过 127.0.0.1 的本地 TCP 端点连接 CLI 和后台服务，不需要创建 Unix socket 文件。
- 音乐模式的 source=system 会读取 Windows 录音设备；如果要捕获电脑播放的声音，请在系统声音设置中启用 Stereo Mix 或安装虚拟回环输入，并将设备名写入 LAMPGO_MUSIC_INPUT_DEVICE。
- 摄像头默认优先使用 DirectShow；多个摄像头时可在设置页填写数字索引，例如 0。

真实硬件从零开始时，建议先阅读 [Windows x64 硬件完整流程](windows-hardware-flow.md)。它特别说明了 COM 自动检测、单舵机写 ID、S3/C6 烧录、断电组装、首次上电和校准的顺序。

## 首次配置

```bash
uv run lampgo onboard
```

向导会依次处理：

| 步骤 | 说明 |
| --- | --- |
| `env_check` | 检查 Python、`uv` 和关键依赖。 |
| `hardware` | 配置电机串口、摄像头、麦克风和 ESP32 无线设备，支持自动探测。 |
| `llm` | 配置 LLM provider、模型、Base URL 和 API key。 |
| `persona_memory` | 导入默认或自定义人设与记忆文件。 |
| `codex` | 自动发现本机 Codex、检查登录并注册 LampGo MCP 工具。 |

配置默认写入：

```text
~/.lampgo/
├── config.toml
├── credentials.json
├── memory/
└── <persona>.md
```

`credentials.json` 保存敏感凭证，请勿提交到仓库。

## 启动 Web 控制台

连接真实硬件：

```bash
uv run lampgo run --web
```

无硬件模式：

```bash
uv run lampgo run --web --no-hw
```

指定端口：

```bash
uv run lampgo run --web --web-port 18790
```

打开 <http://127.0.0.1:8420> 后，可以使用聊天、技能、表情、录制和设置面板。

## 验证安装

另开一个终端执行：

```bash
uv run lampgo status
uv run lampgo skills
uv run lampgo text "点个头"
```

如果没有启动守护进程，`status` 和 `text` 会提示先运行 `lampgo run`。硬件未连接时，运动和 LED 技能会自动跳过真实写入，但 Web 与路由仍可调试。

## 连接真实硬件

### 硬件配网

首次使用 ESP32 LED 控制器、摄像头或麦克风时，需要先把硬件接入和电脑相同的局域网。设备暂不支持 5GHz Wi-Fi，建议准备 2.4GHz Wi-Fi，并确认电脑和硬件在配网过程中距离路由器较近。

1. 给硬件通电，等待设备进入配网模式。如果是干净烧录或已清空旧 Wi-Fi，串口日志会出现 `SSID: Lampgo-Setup-XXXX`。
2. 在电脑的 Wi-Fi 列表中找到 `Lampgo-Setup-XXXX` 设备热点，输入热点密码 `lampgo123` 并保持连接。系统如果提示“无互联网连接”，选择继续连接即可。
3. 打开 YareLampGo Web 控制台，进入设置页的 ESP32 / 无线设备配网向导，点击“我已连上设备热点”。
4. 在配网向导中选择要让台灯连接的 2.4GHz Wi-Fi，输入该 Wi-Fi 的密码，然后点击发送。
5. 发送成功后等待设备重启。设备会关闭临时热点并连接目标 Wi-Fi，此时把电脑切回同一个 2.4GHz Wi-Fi。
6. 等待 Web 控制台重新发现 `lampgo-cam-XXXX.local` 或设备 IP 后，再继续执行下面的软件配置步骤。

| 连接设备热点 | 选择 2.4GHz Wi-Fi | 等待设备回连 |
| --- | --- | --- |
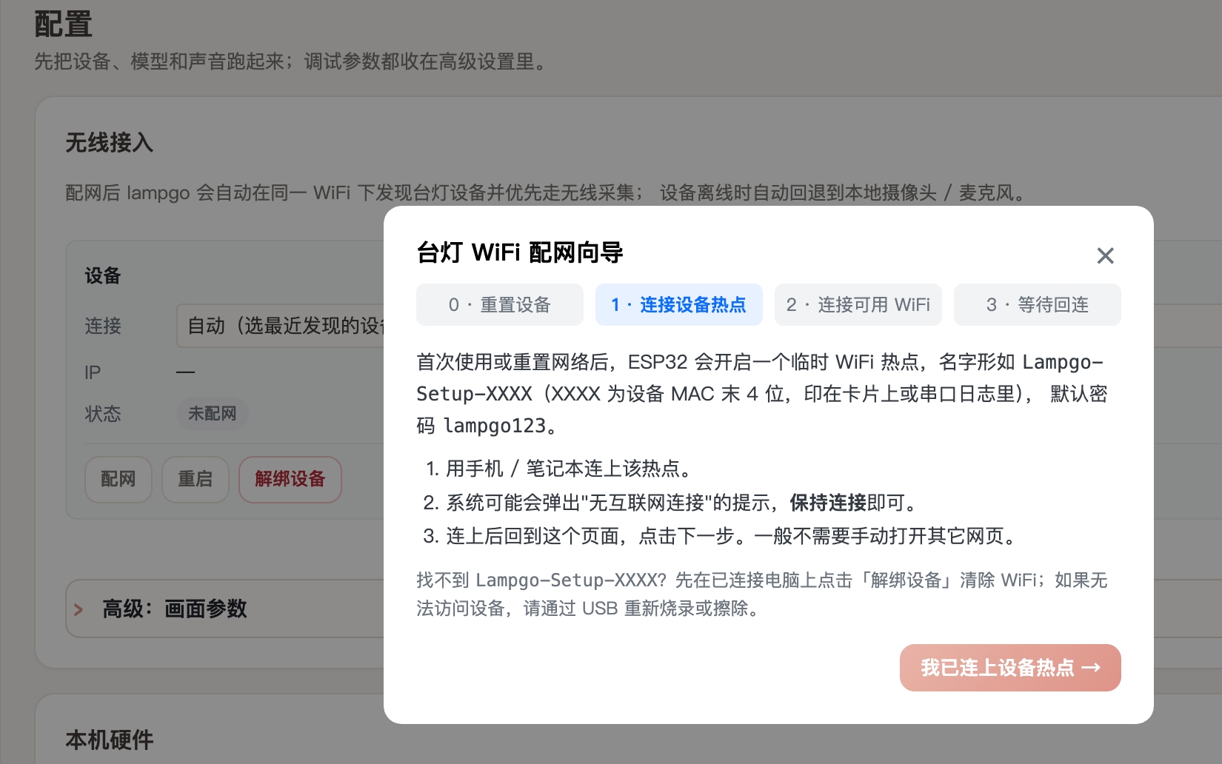
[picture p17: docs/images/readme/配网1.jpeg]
连接设备热点
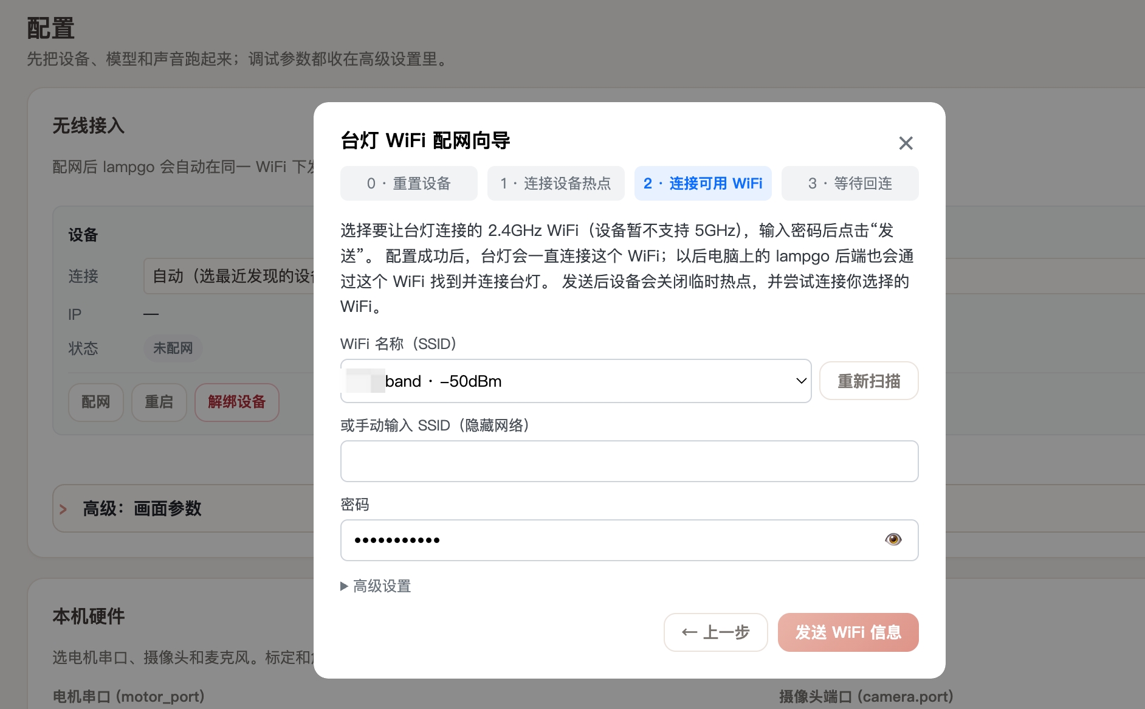
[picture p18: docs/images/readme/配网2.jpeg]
选择可用 Wi-Fi
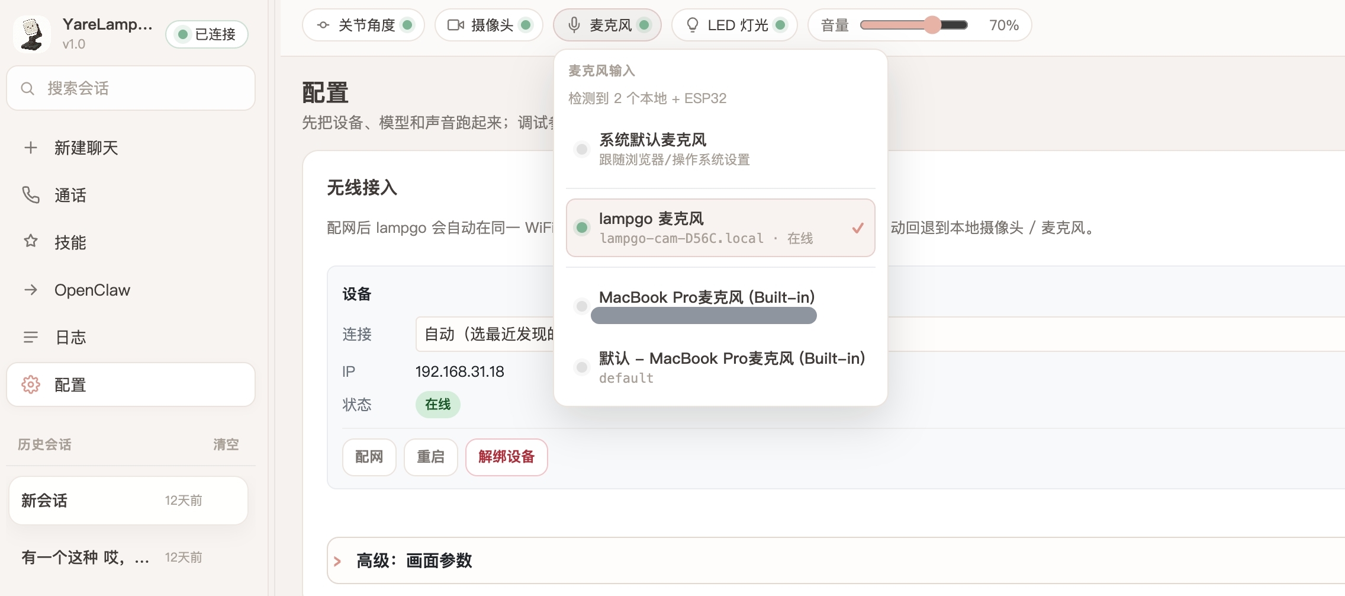
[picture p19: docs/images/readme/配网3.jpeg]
设备回连后选择网络设备
|  |  |  |

> 自动扫描失败时，可检查高级设置里的设备配网页地址是否为 `http://192.168.4.1`。

### 接入 YareLampGo

1. 接入电机总线。
2. 执行 `uv run lampgo detect` 查看候选串口和网络设备。
3. 如果舵机尚未编号，执行 `uv run lampgo setup-motors`；它会优先使用已保存端口，否则自动检测电机 COM。多个候选时按提示选择。
4. 执行 `uv run lampgo scan-motors --auto-detect --ids 1-5` 和 `uv run lampgo ping --auto-detect` 做只读验证。
5. 执行 `uv run lampgo onboard` 或在 Web 设置页写入串口和 ESP32 设备信息。
6. 首次使用新设备时执行 `uv run lampgo calibrate --auto-detect`。
7. 启动 `uv run lampgo run --web`。

常见调试命令：

```bash
uv run lampgo ping --auto-detect
uv run lampgo invoke return_safe
uv run lampgo invoke set_expression expression=heart
uv run lampgo estop
uv run lampgo clear
```

## 下一步

- 阅读 [Windows x64 硬件完整流程](windows-hardware-flow.md) 从零完成 Windows 硬件验收。
- 阅读 [V2.0 手动安装](manual-hardware-setup.md) 完成跨平台舵机编号、固件烧录、首次上电和校准。
- 阅读 [配置说明](configuration.md) 理解配置来源和凭证管理。
- 阅读 [动作与表情](../guides/motion-and-expression.md) 学习录制、回放和 LED 控制。
- 阅读 [Codex 集成](../guides/codex-integration.md) 将台灯接入本机复杂任务工作流。

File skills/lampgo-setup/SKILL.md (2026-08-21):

---
name: lampgo-setup
description: Interactively install, configure, assemble, and validate YareLampGo V2.0 with Codex. Use when the user asks to install LampGo, configure a new lamp, bring up assembled hardware, build the DIY V2 hardware, flash S3/C6, assign servo IDs, calibrate, connect Wi-Fi/LLM/voice/Codex, diagnose first startup, or says LampGo 安装、配置、复刻、装机、配网、烧录、舵机编号、校准、首次启动.
---

# LampGo V2 Setup

Guide the user from their actual starting state to a verified LampGo setup. Execute safe software work directly, but pause at physical or state-changing hardware gates.

## Language routing

- Detect the working language from the user's latest meaningful message, not from the operating-system locale, repository path, or installer output.
- If the user writes Chinese, use clear Simplified Chinese for the entire interaction.
- If the user writes English, use English for the entire interaction.
- If there is no usable language context, default to Simplified Chinese.
- An explicit language request always wins. If the user changes language later, follow the latest explicit preference immediately.
- Keep commands, paths, configuration keys, identifiers, and raw error text unchanged; explain them in the selected language.
- Do not interrupt setup just to ask for a language choice when these rules already resolve it.

## Outcomes

Complete the applicable path and report each item as `verified`, `completed but not verified`, `skipped`, or `blocked`:

- repository and dependency installation
- V2.0 hardware documentation review
- S3/C6 firmware readiness
- five-servo ID assignment and bus scan
- physical assembly and wiring checks
- calibration preservation and new calibration
- Wi-Fi, LLM, voice, and local Codex configuration
- Web startup and end-to-end validation

Do not call a screenshot, a started process, a `200` response, or a visible control button proof of end-to-end readiness by itself.

## Locate the repository

1. If the current directory contains `pyproject.toml`, `install.sh`, and `lampgo/`, use it.
2. Otherwise resolve this `SKILL.md` through symlinks. A repository-installed skill normally lives at `skills/lampgo-setup/SKILL.md`, so the repository root is two directories above the skill directory.
3. If that path is only a copied skill and no repository is present, search the current workspace for `YareLampGo`.
4. If no clone exists and the user asked for installation, clone `https://github.com/ninsmiracle/YareLampGo.git` into a user-approved workspace directory. Do not guess a destination that would overwrite an existing directory.

Before changing files, read:

- `README.md`
- `docs/getting-started/manual-hardware-setup.md` for the complete manual command flow
- `docs/getting-started/windows-hardware-flow.md` for the Windows x64 hardware sequence and COM detection rules
- `docs/hardware/v2/README.md` for hardware routes
- `docs/hardware/wiring.md` before any wiring or first power
- `docs/getting-started/quick-start.md`
- `docs/getting-started/configuration.md`
- the current `install.sh` or `install.ps1`

Read `git status --short --branch`. Preserve user changes, especially `assets/calibration/*.json`, `.env`, and local configuration. Never reset or clean the repository to make installation easier.

## Choose one route

Infer the route from the request. If it is unclear and changes the physical workflow, ask one short question.

### A. Software-only

Use when there is no LampGo hardware yet or the user wants to try the Web UI, Agent, configuration, or skills first.

Skip firmware, servo writes, assembly, real calibration, and real motion. Finish with `uv run lampgo run --web --no-hw`.

### B. Assembled V2.0 unit

Use when the user has a built unit whose servos are already numbered and whose S3/C6 firmware is already installed.

Start with read-only detection. Do not rerun servo assignment, erase flash, or overwrite calibration just because the commands exist.

### C. DIY V2.0 build

Use when the user has loose parts, a new PCB, unnumbered servos, or asks for the complete reproduction path.

Follow this order:

`install software -> assign one servo at a time -> flash S3/C6 -> assemble while unpowered -> verify 12V/+5V/GND -> scan -> calibrate -> onboard -> start`

## Interaction contract

- Begin with a compact checklist showing the selected route and current state.
- Perform read-only checks without repeatedly asking for permission.
- At every manual checkpoint, explain the exact physical condition to establish and ask the user to confirm it.
- After a command, read the real output and update the checklist. Never infer success from a command merely being launched.
- If the user must unplug, connect, hold BOOT, move a joint, inspect a voltage, or type a secret, stop at that step and wait.
- Follow the language-routing rules above. Keep commands copyable.

## Safety gates

Explicit confirmation is required immediately before each of these actions:

1. writing a persistent servo ID or bus baud rate
2. firmware upload, especially an erase flash
3. applying 12V for the first time after wiring or structural work
4. replacing or creating calibration for an existing `lamp_id`
5. enabling torque or issuing the first real motion

The confirmation must state the physical preconditions, not just ask “continue?”

Never:

- run `setup-motors` with more than one unconfigured/repeated-ID servo on the bus
- change servo wiring while 12V is present
- insert S3, C6, LED, or amplifier modules before verifying the +5V rail on a new board
- assume USB and external +5V may be applied together without backfeed protection
- run a large motion before calibration and a small-range test
- bypass LampGo's safety kernel by directly commanding the servo SDK
- print or open `~/.lampgo/credentials.json` in chat or logs
- place API keys in shell history, command arguments, repository files, or screenshots

## Phase 1: Read-only preflight

Collect and summarize:

- OS, CPU architecture, shell, and Windows/macOS/Linux version
- repository path, branch, commit, and dirty files
- available `git`, `curl`/`wget`, PowerShell, and USB/serial tooling
- whether `uv` is present; the installer remains authoritative even when it is not
- existing `~/.lampgo/config.toml` without exposing secrets
- candidate serial ports and whether another process owns them
- whether ports `8420` and `18790` already have listeners and which processes own them
- selected hardware route and physical readiness

Do not use a stale LampGo process as evidence that the current checkout works.

## Phase 2: Install software

Use the repository installer, not an improvised dependency command.

macOS/Linux:

```bash
./install.sh
```

Windows PowerShell:

```powershell
powershell -ExecutionPolicy Bypass -File .\install.ps1
```

The installer pins/bootstraps `uv`, prepares Python 3.12, and installs the lockfile-defined default dependency set, including voice support. Do not replace this with a generic `pip install` or an unquoted extra.

Verify at minimum:

```bash
uv --version
uv run python --version
uv run lampgo help
```

If install fails, report the failing stage and the newest log under `~/.lampgo/logs/`. Diagnose declaration, lockfile, installer behavior, runtime import, and platform constraints as one chain.

For route A, proceed directly to onboarding and no-hardware validation.

## Phase 3: Assign the five servo IDs (DIY only)

Show the mapping before any write:

| Position | Program name | ID |
| --- | --- | ---: |
| Base rotation | `base_yaw` | 1 |
| Base pitch | `base_pitch` | 2 |
| Elbow pitch | `elbow_pitch` | 3 |
| Wrist roll | `wrist_roll` | 4 |
| Wrist pitch | `wrist_pitch` | 5 |

Start one interactive PTY session with `uv run lampgo setup-motors`. The command uses an explicit `--port <port>` first, then the saved `device.motor_port`, then Feetech-aware serial detection. On Windows, `COM` ports are probed automatically; use `--auto-detect` (or `--rescan`) to ignore a stale saved port and force a fresh scan. If multiple ports remain ambiguous, let the user choose from the numbered candidates or ask for an explicit `--port`; never guess. The command itself walks through the five positions. At every position prompt:

1. Ask the user to remove 12V.
2. Ask them to connect exactly one servo to the bus adapter.
3. Ask them to identify the intended physical position shown by the current prompt.
4. Restore power only after they confirm the single-servo condition.
5. Continue the existing PTY prompt and read back the write/verification result.
6. Remove 12V before allowing the command to advance to the next servo.

Do not relaunch the full five-servo wizard once per motor. If the session aborts partway through, inspect the IDs already written before deciding where to resume.

After all five writes, connect the completed chain and run:

```bash
uv run lampgo scan-motors --auto-detect --ids 1-5
```

Require one unique response for every ID. Duplicate, missing, or unstable IDs block assembly/calibration until resolved.

## Phase 4: Firmware readiness

Firmware lives in the separate `YareLampGo_esp32` repository. Inspect its current README and scripts before using commands; do not rely on copied commands if that repository has changed.

S3 typical flow:

```bash
./scripts/flash.sh --list-ports
./scripts/flash.sh --port <S3_PORT> --erase --monitor
```

Use `--erase` only for first installation or deliberate recovery, after confirmation that saved Wi-Fi/device state may be lost.

C6 typical flow:

```bash
arduino-cli compile --upload \
  --port <C6_PORT> \
  --fqbn esp32:esp32:esp32c6:FlashSize=8M \
  ESP32_C6_LCD_1_47_UART
```

Confirm S3 and C6 ports separately. A successful compile is not a successful upload; a successful upload is not proof that UART, display, audio, camera, or Wi-Fi works in the assembled unit.

## Phase 5: Assembly and electrical checkpoint

Open `docs/hardware/v2/YareLampGo_V2.0_assembly_manual.md` for the GitHub-readable illustrated sequence and `docs/hardware/v2/README.md` for searchable notes. The DOCX remains the source download when offline viewing or printing helps.

The user must confirm all of the following before first 12V power:

- V2.0 parts are not mixed with V1.0 parts
- motor cables are inside the intended channels and clear of gears, axes, and pinch points
- the support-arm cable holes are used and full joint travel does not tension the harness
- S3 GPIO43 TX crosses to C6 RX, and S3 GPIO44 RX crosses from C6 TX
- U3 LED pin order matches the physical connector orientation
- 12V and +5V rails are not swapped, all logic grounds are common, and polarity has been checked
- with logic modules removed, the power module measures +5V to GND
- fasteners/inserts are seated and no loose metal can short the PCB

The schematic PNGs are not fabrication outputs. If the user intends to order a PCB, stop and explain that Gerbers, drill files, placement data, a production BOM, and editable EDA source are not present in this release.

## Phase 6: Preserve configuration and calibrate

Run calibration from the LampGo repository root. The CLI intentionally aborts before touching hardware when launched from another directory.

Run read-only detection first:

```bash
uv run lampgo detect
uv run lampgo scan-motors --auto-detect --ids 1-5
uv run lampgo ping --auto-detect
```

Before calibration:

1. Determine the intended `device.lamp_id`.
2. Check `git status --short -- assets/calibration`.
3. If `assets/calibration/<lamp_id>.json` exists, copy it to a timestamped directory under `~/.lampgo/backups/calibration/` and report the backup path.
4. Never stage, commit, discard, or silently replace a user's calibration file.
5. Ask the user to support the mechanism, clear its motion envelope, keep joints away from hard stops, and prepare the 12V disconnect/estop.
6. Obtain explicit confirmation, then run `uv run lampgo calibrate --auto-detect`, adding `--port` if needed.

After calibration, read back the selected lamp ID and resulting calibration path. Validate with a small movement only after the user confirms the area is clear. Prefer `return_safe` or a small single-joint test; do not begin with a dance or full-range action.

## Phase 7: Onboard and configure

Run the interactive wizard in a PTY when available:

```bash
uv run lampgo onboard
```

Cover these sections:

- `env_check`: Python, uv, imports, and runtime readiness
- `hardware`: motor port, lamp ID, local/ESP32 camera, microphone, and network device
- `llm`: provider, base URL, model, and connectivity
- `persona_memory`: persona and memory choice
- `codex`: local Codex discovery, login, and idempotent LampGo MCP registration

Credential handling:

- Let the user type keys in the onboard prompt or Web settings page.
- Do not ask the user to paste secrets into chat.
- Do not display credential files. It is enough to verify file existence, permissions, and a redacted field-presence summary.
- Confirm `~/.lampgo/credentials.json` permissions are appropriately restricted on POSIX systems.

For a clean S3 or an erased device, guide the user through the Web Wi-Fi wizard: connect to `Lampgo-Setup-XXXX`, use the documented device-hotspot password, select the same 2.4 GHz network as the computer, then reconnect the computer and wait for device rediscovery. Never echo the user's Wi-Fi password.

For voice, verify the whole chain: installed voice dependencies, current local process/port ownership, SDK readiness, cloud/service connectivity when configured, browser relay, and the ESP32 audio endpoints. A lone `/healthz` response is insufficient.

## Phase 8: Start and verify

Software-only:

```bash
uv run lampgo run --web --no-hw
```

Real hardware:

```bash
uv run lampgo run --web
```

Verify from a separate process:

```bash
uv run lampgo status
uv run lampgo skills
```

Also confirm the current LampGo process owns port 8420, the Web page loads from the current checkout, the expected hardware is detected, and the task can invoke a safe small action. For no-hardware mode, run a text/skill routing check without claiming physical execution.

For real hardware, the final acceptance ladder is:

1. five unique servos detected
2. current calibration loaded for the selected unit
3. safe small motion completes without stall or wrong direction
4. `return_safe` completes
5. S3 network device is current and LED command is acknowledged
6. C6 display UART produces the expected update
7. camera/microphone/audio are tested only if the user selected those features
8. Codex status is connected and a read-only LampGo MCP call succeeds

Stop immediately on wrong direction, unexpected range, cable tension, stall, overheating, repeated timeouts, or supply instability.

## Final report

Return a compact table with:

- component/stage
- observed result
- evidence or command
- status (`verified`, `completed but not verified`, `skipped`, `blocked`)
- next action

Always list:

- repository path and commit
- selected route
- config and calibration paths without secrets
- any physical step the user still owes
- any feature not tested
- the exact safe restart command

Do not describe the setup as complete while any required physical confirmation, calibration, or selected feature validation remains outstanding.

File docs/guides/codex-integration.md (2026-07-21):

# Codex 集成

LampGo 把本机 Codex 当作复杂任务执行器。Codex 已安装并登录时，用户只需启动 LampGo：

```bash
uv run lampgo run --web
```

启动过程会自动查找 PATH、ChatGPT App 和 Codex App 中的 CLI，检查登录状态，并幂等注册 `lampgo` stdio MCP。用户不需要配置 token、端口、环境变量或编辑 `~/.codex/config.toml`。

## 用 Codex 完成首次装机

仓库还提供一个面向首次安装/装机的 `lampgo-setup` skill。它和运行时 MCP 分工不同：skill 带用户完成依赖、V2.0 硬件检查、烧录、校准、配网和配置；运行时 MCP 则让已经启动的 LampGo 接受 Codex 工具调用。

macOS / Linux：

```bash
./install-codex-skill.sh
```

Windows PowerShell：

```powershell
powershell -ExecutionPolicy Bypass -File .\install-codex-skill.ps1
```

新建 Codex 任务后说：

```text
用 $lampgo-setup 帮我安装和配置 YareLampGo V2.0
```

skill 会选择纯软件、已组装成品或 DIY V2.0 路线，并在写舵机 ID、擦除烧录、首次 12V、校准和真实运动前要求明确的物理确认。skill 文件见 [`skills/lampgo-setup/SKILL.md`](../../skills/lampgo-setup/SKILL.md)。

## 通信链路

```text
LampGo -- codex exec --json --> Codex
Codex  -- stdio MCP ---------> lampgo mcp-stdio
lampgo mcp-stdio -- authenticated localhost HTTP --> LampGo daemon
LampGo -- WebSocket events --> Web console
```

复杂任务由 `AgentManager` 保存和调度。只读分析默认使用 Codex `read-only` sandbox；明确包含修改、实现、修复、创建等意图的任务使用 `workspace-write`。所有台灯动作仍由 LampGo daemon 执行，并经过原有的 SkillExecutor、MotionRuntime 和 SafetyKernel。

LampGo 聊天框是任务的主显示面，不要求 `codex exec` 创建的任务出现在 Codex Desktop 侧边栏。执行过程中，聊天框会显示 Codex 主动给用户的阶段说明，以及搜索、命令、工具调用和文件修改的简短状态；隐藏思维链、加密 reasoning、工具参数、完整终端输出和疑似密钥不会回传。最终答案会作为一条新的助手消息自动写回发起任务的原会话。

实时状态优先走 WebSocket；只要存在排队中或执行中的任务，网页还会每 2 秒读取一次 `/api/agent/tasks` 作为看门狗。WebSocket 半断开、浏览器短暂休眠或漏收完成事件时，看门狗和事件回放都能补齐任务状态并投递最终答案，无需用户手动刷新。

用户说“把 Codex 叫来”“把你大哥叫来”“交给 Codex”“让 Codex 来”等明确召唤语时，路由层会跳过快速 LLM 判断，直接把原始任务交给本机 Codex。只是在对话中提到 Codex 或“大哥”不会误触发。

## LED 任务状态

Codex 任务状态通过事件总线映射到灯板现有表情，不让 AgentManager 直接依赖硬件：

- `queued` / `running` / `cancelling` → `focused`（专注）
- `completed` → `check`（对号）
- `failed` / `cancelled` / `interrupted` → `cross`（叉号）

如果同时有多个 Codex 任务，只要还有一个任务在进行，灯板就保持“专注”；全部结束后才显示最后一个结束任务的结果。LED 网络调用在独立后台队列里串行执行，不阻塞 Codex 的进度事件或用户回复。

## 自动鉴权

LampGo 会在 `~/.lampgo/credentials.json` 中生成本机随机 token，文件权限为 `0600`。`lampgo mcp-stdio` 自己读取 token 并添加到 localhost 请求中，Codex 配置和用户 shell 都不保存 token。

## Codex 记忆

LampGo 的同步回复热路径只读取：

```text
~/.codex/memories/memory_summary.md
```

文件按 mtime 缓存在内存中，并按当前问题选择最多约 6 KB 的相关 Markdown 段落。LampGo 不在热路径读取完整 `MEMORY.md`、会话数据库、rollout 日志或推理记录。

可在 Web 配置页关闭“参考 Codex 摘要”。文件不存在或读取失败时，LampGo 会直接忽略，不影响正常回复。

## MCP 工具

- `lampgo_status`
- `lampgo_list_skills`
- `lampgo_invoke`
- `lampgo_camera_snap`
- `lampgo_ask_user`
- `lampgo_agent_tasks`

## 故障提示

Web 控制台的 Codex 页面会显示以下状态：

- `已接通`：CLI、登录和 MCP 均就绪。
- `请登录 Codex`：打开 Codex 完成登录即可。
- `未安装 Codex`：本机没有检测到 Codex CLI。
- `连接异常`：自动注册失败；详情卡会显示原因。

运行状态也会打印在 LampGo 启动横幅中。`--no-hw` 模式可用于验证完整的软件链路，不会连接真实电机或 LED。

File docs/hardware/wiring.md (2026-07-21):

# YareLampGo V2.0 接线指南

本页是 V2.0 当前接线基线。先完成断电检查，再接 12V 舵机电源；不要用 V1.0 接线图推断 V2.0 主板。

完整电路图说明见 [V2.0 硬件指南](v2/README.md)。原始图片在 [`v2/schematics/`](v2/schematics/)。

## 电源域

| 电源域 | 对象 | 要求 |
| --- | --- | --- |
| 12V | 五颗 STS3215 舵机和舵机总线供电 | 只接主板/电源模块标明的 12V 输入。上电前核对正负极。 |
| +5V | XIAO ESP32-S3、ESP32-C6 LCD、MAX98357A、LED 灯板 | 由 V2.0 电源模块输出；安装逻辑板前先用万用表确认。 |
| GND | 舵机电源、5V 逻辑、S3、C6、功放、LED | 必须共地。任何信号线接入前先确认地线连续。 |

> 主板同时包含 12V 舵机侧和 +5V 逻辑侧。未确认电压时不要插入 S3、C6、LED 或功放。外部 +5V 与 USB 同时供电可能回灌，除非已确认硬件具备隔离/防反灌设计，否则二选一。

## S3 信号映射

| XIAO ESP32-S3 引脚 | 网络名 | 连接对象 | 作用 |
| --- | --- | --- | --- |
| D0 / GPIO1 | `I2S_BCLK` | MAX98357A BCLK | I2S 位时钟 |
| D1 / GPIO2 | `I2S_LRCLK` | MAX98357A LRCLK | I2S 左右声道时钟 |
| D2 / GPIO3 | `DIN` | LED 板 DIN | LED 串行数据 |
| D3 / GPIO4 | `I2S_DOUT_AMP` | MAX98357A DIN | I2S 音频数据输出 |
| D6 / GPIO43 / TX | `S3TX_C6RX` | C6 RX | 屏幕串口：S3 发、C6 收 |
| D7 / GPIO44 / RX | `S3RX_C6TX` | C6 TX | 屏幕串口：S3 收、C6 发 |
| VBUS | `+5V` | 5V 电源域 | S3 供电 |
| GND | `GND` | 公共地 | 逻辑参考地 |

## C6 LCD 排针

| 接口 | 引脚 | 网络名 | 连接 |
| --- | ---: | --- | --- |
| U1 | 1 | `S3RX_C6TX` | C6 TX → S3 GPIO44 RX |
| U1 | 2 | `S3TX_C6RX` | S3 GPIO43 TX → C6 RX |
| U2 | 9 | `VBUS` | +5V |
| U2 | 8 | `GND` | 公共地 |

其余 U1/U2 引脚在当前公开图中标记为不连接。固件中使用的 C6 UART GPIO 仍以固件仓库版本为准，不要只凭排针位置猜测。

## 功放和喇叭

V2.0 主板给出两种兼容方式：板载 MAX98357A 方案，以及 H4 五针功放模块接口。只安装一种实际功放路径，避免重复驱动。

| 网络 | MAX98357A | H4 模块接口 |
| --- | --- | --- |
| +5V | VDD 7/8，`GAIN_SLOT` 2 | `+5V` |
| GND | GND 3/11/15 和 EP | `GND` |
| `I2S_BCLK` | BCLK 16 | `BCLK` |
| `I2S_LRCLK` | LRCLK 14 | `LRCLK` |
| `I2S_DOUT_AMP` | DIN 1 | `DOUT_AMP` |

板载方案中 `SD_MODE#` 通过 1 MΩ 上拉到 +5V。`OUTP` / `OUTN` 接 CN7 两针喇叭端子；喇叭两端都属于桥接输出，不要把其中一端接地。

## LED 接口 U3

| U3 引脚 | 网络 |
| ---: | --- |
| 5 | GND |
| 4 | GND |
| 3 | `DIN` |
| 2 | +5V |
| 1 | +5V |

两组 +5V/GND 用于分担供电连接，但实际线束针序必须与实物连接器方向一致。接反 +5V/GND 会损坏灯板。

## 舵机总线

五颗 STS3215 依次串联。组装前一次只连接一颗新舵机并写入 ID：

| 位置 | 程序名称 | ID |
| --- | --- | ---: |
| 底座水平旋转 | `base_yaw` | 1 |
| 底座俯仰 | `base_pitch` | 2 |
| 肘部俯仰 | `elbow_pitch` | 3 |
| 手腕滚转 | `wrist_roll` | 4 |
| 手腕俯仰 | `wrist_pitch` | 5 |

```bash
uv run lampgo setup-motors
```

执行时总线上只能有一颗舵机；换线前必须断开 12V。

## 首次上电检查

1. 断开 S3、C6、LED 和功放，确认 12V 输入正负极。
2. 只给电源板上电，测量 +5V 对 GND；电压不正确立即断电。
3. 断电后安装逻辑板，检查所有连接器方向、冷焊/短路和线束夹点。
4. 先用 USB 分别验证 S3、C6 固件，再接入整机 +5V。
5. 扶稳机构，保持所有关节远离机械限位，再接 12V 舵机电源。
6. 先运行 `uv run lampgo detect` 和 `uv run lampgo scan-motors --ids 1-5`，五颗舵机都在线后才校准。

电路 PNG 是连接和审查参考，不是可直接下单的 Gerber、钻孔、坐标或 BOM 文件。

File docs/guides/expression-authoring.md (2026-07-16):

# LampGo Expression Authoring

LampGo expressions are reusable compositions, not a single animation file:

- `EyeClip` is a 320x172 C6 LCD asset containing eyes only.
- `LedEffect` is either an immutable firmware effect or a safe color pixel clip
  uploaded to the S3 for a mouth, symbol, direction, or accent.
- `ExpressionPreset` references one optional eye and one optional LED effect.

At least one channel must be present. The two channels start at `t=0` and use
the same 0-1 phase over a default three-second duration. Expressions loop by
default and keep looping for the full action; callers must explicitly request
`once` when they want a one-shot micro-expression.

## Design Rules

1. Keep the C6 image black except for the eyes. Do not draw a mouth, product
   shell, LED board, text, or status UI into an eye sprite.
2. Use the front-facing 51x9 LED grid for mouths, arrows, hearts, symbols, and
   broad color accents. Twelve corner cells are outside the physical 447-pixel
   topology and are ignored by the compiler.
3. User effects use LED program version 2 (`pixel_clip`): exactly 30 ticks at
   10fps, up to 16 RGB colors including the off color, and no executable code.
4. Use 30 eye frames at 10fps and target 3.0 seconds. The accepted range is
   8-12fps and 2.5-3.5 seconds.
5. A transient composition may be previewed or played without being saved.
   An LLM must receive explicit user confirmation before saving a preset.
6. Do not emit arbitrary code, jumps, unbounded loops, or device allocations.
   Repeated frames use `ticks`; their sum must be exactly 30. Firmware v1
   templates remain available only for official and backward-compatible assets.

## Pixel Clip Format

```json
{
  "effect_id": "rainbow_smile",
  "label": "Rainbow smile",
  "role": "mouth",
  "program": {
    "version": 2,
    "type": "pixel_clip",
    "fps": 10,
    "palette": {".": "#000000", "1": "#ff3366", "2": "#00d8ff"},
    "roles": {"primary": "1", "secondary": "2"},
    "frames": [{
      "rows": [
        "...................................................",
        "...................................................",
        "...................................................",
        "...................................................",
        "..........1111111111111111111111111111111..........",
        "...................................................",
        "...................................................",
        "...................................................",
        "..................................................."
      ],
      "ticks": 30
    }]
  }
}
```

Palette symbols are `.123456789ABCDEF`; `.` is always off. The backend maps
the logical grid to physical wiring, deduplicates frames, compiles LEF1, and
rejects packages over 8KiB. `primary`, `secondary`, and `accent` palette roles
may be recolored by a preset without copying the animation.

## Capacity Contract

- Eye package: at most 256KiB.
- Current C6 partition: 5 eyes, 896KiB installed budget, 256KiB reserve.
- Product C6 partition: 10 eyes, 3MiB installed budget, 1MiB reserve.
- S3 custom LED effects: 24 files, 8KiB each, 192KiB total.
- S3 presets: 64 files, 1KiB each, 64KiB total.
- Composition brightness is capped at 96 to protect the shared power and Wi-Fi
  stability envelope. The normal default is 64.
- The device rejects writes that cross a quota. It never evicts another asset.

The S3 keeps LCD uploads only as staging data. After the C6 acknowledges size
and SHA256 validation, the S3 removes its LCD copy. The C6 writes to a temporary
file and replaces the installed eye only after validation succeeds.

## Runtime Discovery

Agents must query the live catalog before choosing ids:

```text
GET /api/eyes
GET /api/led-effects
GET /api/expression-presets
GET /api/device/expression-capabilities
GET /api/expression-catalog
```

The same catalog is atomically written to
`~/.lampgo/expression_library/llm-catalog.json` for local agents that cannot
call the HTTP API. It is a generated read-only projection, not a second source
of truth.

Play a saved preset:

```json
POST /api/expressions/play
{"preset_id":"dizzy"}
```

Play a transient composition without saving it:

```json
POST /api/expressions/play
{
  "eye_clip_id": "dizzy_eyes",
  "led_effect_id": "arrow",
  "led_params": {
    "direction": "right",
    "color": "#00ff88",
    "brightness": 64,
    "intensity": 0.8
  },
  "playback": "loop",
  "duration_ms": 3000
}
```

Save only after the user confirms:

```json
POST /api/expression-presets
{
  "name": "Dizzy right",
  "eye_clip_id": "dizzy_eyes",
  "led_effect_id": "arrow",
  "led_params": {"direction":"right","color":"#00ff88"},
  "playback": "loop",
  "duration_ms": 3000,
  "confirmed": true
}
```

The backend generates a stable `preset_id` when it is omitted. Renaming a
preset changes its display name, not the stable ids referenced by recordings.

Create and upload a user LED effect through the backend:

```text
POST /api/led-effects
POST /api/led-effects/{effect_id}/sync
```

Playback automatically compares the installed S3 SHA and performs the small
LEF1 upload when the selected user effect is missing or stale. Official effects
remain in firmware and cannot be overwritten or deleted.

The legacy `dizzy` cache is exposed without copying binary data as
`dizzy_eyes + dizzy_mouth -> dizzy preset`. Existing `clip_id=dizzy` callers
continue to work.

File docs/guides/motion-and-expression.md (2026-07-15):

# 动作与表情

YareLampGo 把真实硬件控制包装成技能。上层用户、Web UI、CLI、本地 LLM 和 Codex 都通过技能调用运动、表情、录制和组合动作，避免绕过安全内核直接写电机。

## 内置动作

常用动作：

```bash
uv run lampgo invoke return_safe
uv run lampgo invoke nod
uv run lampgo invoke headshake
uv run lampgo invoke look_at yaw=20 pitch=-10
uv run lampgo invoke idle_sway
uv run lampgo invoke dance
uv run lampgo invoke cat_teaser marker_color=red duration=60
```

自然语言入口：

```bash
uv run lampgo text "点个头"
uv run lampgo text "看向左边"
uv run lampgo text "跳个舞"
```

`IntentRouter` 会先尝试关键词匹配；未命中时再进入 LLM tool calling；本地快速路径无法稳妥完成的复杂任务会交给 Codex。

## 直接移动关节

```bash
uv run lampgo move base_yaw=30 base_pitch=-20
uv run lampgo move elbow_pitch=-40 wrist_pitch=20 --velocity 90
```

关节命令仍会经过 `MotionRuntime` 和 `SafetyKernel`，包括关节限位、速度上限、加速度上限和急停状态检查。

## 逗猫棒互动

`cat_teaser` 是本地视觉实时技能。请在逗猫棒末端贴一个与 `marker_color` 一致的明显标记（默认 red），并让灯头摄像头能看到标记。

```bash
uv run lampgo invoke cat_teaser marker_color=red duration=60
uv run lampgo invoke cat_teaser marker_color=magenta duration=60
```

它会用 OpenCV 在本机识别标记位置，并根据标记附近的运动能量估计 `searching`、`teasing`、`engaged`、`pounce`、`caught`、`rest`、`unsafe_close` 等状态。运行时默认弹出 `LampGo Cat Teaser Vision` 调试窗口，窗口里会显示摄像头画面、标记圈、运动质心、状态、motion/engagement 分数；按 `q` 或 `esc` 可停止本次逗猫。终端会打印类似 `[cat_teaser] 12.4秒有触碰动作 ...` 的事件日志，便于判断是摄像头没看到标记、颜色参数不匹配，还是状态机阈值需要调。

默认还会把硬件摄像头画面保存为 MP4：`recording_dir=""` 时写到 `~/.lampgo/cat_teaser_recordings/<时间>-<颜色>/cat_teaser.mp4`，同目录的 `frames.jsonl` 会记录每帧状态和触碰事件，方便回看排查。`--no-hw` 模式下不会保存电脑摄像头视频。

检测到扑击、遮挡或距离过近时会短暂停顿或撤离；摄像头不可用或未安装 perception extra 时会返回明确错误。如果只想后台运行，可以加 `debug_view=false`，如果只想关闭中文事件日志，可以加 `log_events=false`。

在 `--no-hw` 无硬件模式下，如果没有配置 LampGo/ESP32 灯头摄像头，`cat_teaser` 会尝试用电脑本机摄像头 `local://0` 作为 fallback，只运行视觉算法和虚拟动作；Web 弹窗会明确标注当前没有 LampGo 本体硬件，并禁用本次视频保存。

## LED 表情

```bash
uv run lampgo invoke set_expression expression=heart
uv run lampgo invoke set_expression expression=smiley
uv run lampgo invoke set_expression expression=thinking
```

可用表情以代码中的 `LED_EXPRESSIONS`、技能列表和 Web UI 面板为准。Codex 可通过 `lampgo_list_skills` 动态读取当前能力。

## 录制动作

录制时会释放力矩，用户可以手动摆动机械臂。按 `Ctrl+C` 结束录制。

```bash
uv run lampgo record my_action --fps 30
```

默认保存到用户动作目录；内置动作位于：

```text
assets/recordings/
```

回放：

```bash
uv run lampgo play my_action
uv run lampgo invoke play_recording name=my_action
```

回放查找顺序：

```text
assets/recordings/user/<name>.csv
assets/recordings/<name>.csv
```

也可以指定目录：

```bash
uv run lampgo play my_action --recordings-dir ./my-recordings
```

## 运动范式

### 目标驱动

适合只知道终点的动作，例如看向、回安全位、单关节移动。

```text
move_to(target) -> TrajectoryPlan -> SafetyKernel -> HAL
```

典型入口：

- `move`
- `move_to`
- `look_at`
- `return_safe`

### 轨迹驱动

适合已知完整帧序列的动作，例如录制 CSV、舞蹈、点头、摇头。

```text
stream_frames(frames, fps) -> playback tracking -> SafetyKernel -> HAL
```

录制动作不要拆成大量 `move_to` 循环，否则每段都会重新规划，容易产生顿挫。

## 组合技能

组合技能可以把多个基础技能串起来，形成可复用动作。示例文件：

```text
docs/examples/user_skill_welcome_home.json
docs/examples/user_skill_side_wiggle.json
```

组合技能的规则见 [组合技能说明](../composed_skills.md)。

## 安全建议

- 新设备首次运行前先 `calibrate`。
- 录制和回放前保持桌面空间干净。
- 调试未知动作时先降低速度，并保证 `estop` 可用。
- 不在上层 Agent 中暴露裸串口写入能力。
- 硬件异常、卡滞或运动方向不符合预期时立即执行 `uv run lampgo estop`。

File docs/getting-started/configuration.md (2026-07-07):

# 配置说明

YareLampGo 的本地配置推荐通过 `uv run lampgo onboard` 和 Web 控制台维护。仓库中的 `lampgo.toml.example` 只是字段参考，不会被运行时自动读取。

## 配置优先级

运行时真实优先级从高到低：

```text
CLI 参数 > Shell 环境变量 > 项目 .env > ~/.lampgo/credentials.json > ~/.lampgo/config.toml > 内置默认值
```

Web 控制台本身不是一个独立优先级。它会把普通配置写入 `~/.lampgo/config.toml`，把 LLM API Key 写入 `~/.lampgo/credentials.json`，并在保存后尽量热更新当前进程。若同一字段被 CLI 参数或环境变量覆盖，Web 设置页会显示覆盖提示，保存到本地文件后也不会立刻压过更高优先级。

常用 CLI 覆盖方式：

```bash
uv run lampgo run --web --motor-port /dev/tty.usbmodem1101
uv run lampgo run --web --lamp-id AL02
uv run lampgo run --web --web-port 18790
```

环境变量 `LAMPGO_HOME` 可用于测试或多实例隔离：

```bash
LAMPGO_HOME=/tmp/lampgo-dev uv run lampgo run --web --no-hw
```

## 文件位置

```text
~/.lampgo/
├── config.toml          # Web / onboard 写入的本地配置覆盖
├── credentials.json     # LLM API Key，权限应为 0600
├── memory/              # 长期记忆和每日记忆
└── <persona>.md         # 当前人设文件
```

`~/.lampgo/config.toml` 和 `~/.lampgo/credentials.json` 都是本机私有文件，不要提交到仓库。火山引擎 App ID / Access Token 目前由 Web 设置页写入本地配置文件，也应按敏感信息处理。

## Web 端配置入口

启动 Web 控制台后打开 <http://127.0.0.1:8420>，进入 `设置` 页。常用配置都建议从这里保存。

### 硬件

硬件页可以配置：

- `无线接入`：ESP32 设备自动发现或指定 `lampgo-cam-XXXX.local` / IP，调整画面尺寸、JPEG 画质和 HTTP 超时。
- `本机硬件`：电机串口 `device.motor_port`、本地摄像头 `camera.port`、本地麦克风 `voice.mic_device`。
- `高级`：设备标识 `device.lamp_id`、角度单位 `device.use_degrees` 和堵转保护 `device.max_torque_pct`。
- `运动 / 安全`：默认动作速度、动作风格、待机随机摆动、安全速度和安全加速度。

### 模型

模型页包含两类软件配置：

- `LLM 模型`：Provider、Base URL、API Key、主模型、快速模型、消息格式、上下文窗口、输出 token、历史轮数、温度和超时。
- `声音和唤醒`：火山引擎 TTS / ASR、Edge TTS 回退、火山 App ID / Access Token、唤醒词、通话模式和回声保护。

LLM 保存后下一条消息即可生效；火山引擎和语音相关字段保存后会重建语音链路。Web 端口这类服务监听配置保存后需要重启 `lampgo run --web`。

## 配置 LLM

推荐从 Web 控制台配置：

1. 打开 `设置 -> 模型 -> LLM 模型`。
2. 选择 `Provider`。内置选项包括 `MiMo`、`OpenRouter`、`Anthropic`、`OpenAI`、`DeepSeek`、`Google`、`Ollama` 和 `自定义`。
3. 如果选择 `MiMo`，先参考 [Xiaomi MiMo API Open Platform](https://platform.xiaomimimo.com/docs/zh-CN/welcome) 注册并获取 API Key，也可以在官方文档里查看模型、限速和 OpenAI / Anthropic 兼容接口说明。
4. 检查 `Base URL`。内置 Provider 会自动填入默认地址；自定义代理、Azure 网关或私有网关需要手动填写。
5. 填写 `API Key`。密钥会保存到 `~/.lampgo/credentials.json`，不会写入 `config.toml`。
6. 填写 `主模型`。第一次使用建议先保持 Provider 默认模型。
7. 点击 `测试连接`。成功后点击 `保存并生效`。

高级项通常保持默认即可：

```toml
[llm]
provider = "mimo"
message_type = "openai"
api_base = "https://api.xiaomimimo.com/v1"
model = "mimo-v2.5"
fast_model = "mimo-v2.5"
enable_thinking = false
context_window = 200000
max_tokens = 20000
summary_max_tokens = 20000
history_turns = 30
temperature = 0.3
timeout_s = 300.0
```

也可以用环境变量临时覆盖：

```bash
export LAMPGO_LLM_API_KEY="api-key-placeholder"
export LAMPGO_LLM_PROVIDER="mimo"
export LAMPGO_LLM_MODEL="mimo-v2.5"
export LAMPGO_LLM_API_BASE="https://api.xiaomimimo.com/v1"
```

## 配置火山引擎语音

火山引擎用于语音识别和语音播报：

- `stt_provider = "volcengine"`：语音转文字，默认模型为 `bigmodel`。
- `tts_provider = "volcengine"`：文字转语音，需要 App ID / Access Token。
- 未配置火山凭证或改选 `edge-tts` 时，聊天播报会回退到 Edge TTS。

开通服务前先准备火山引擎账号。可参考 [豆包语音快速入门](https://www.volcengine.com/docs/6561/163043?lang=zh) 完成账号注册、实名认证、创建应用和服务开通；如果找不到 App ID / Access Token，可参考 [豆包语音控制台使用 FAQ](https://www.volcengine.com/docs/6561/196768?lang=zh) 查看参数位置。YareLampGo 当前需要填写的是旧版控制台兼容参数 `App ID` 和 `Access Token`。

开通时建议确认应用已启用这些能力：

- [大模型录音文件极速版识别](https://www.volcengine.com/docs/6561/1631584)：`volc.bigasr.auc_turbo`。用于 Web 录音、唤醒链路等短音频识别，接口会一次请求直接返回结果。
- [大模型流式语音识别](https://www.volcengine.com/docs/6561/1354869?lang=zh)：`volc.bigasr.sauc.duration`。用于实时通话 / LiveKit 语音链路。
- [豆包语音合成大模型 2.0](https://www.volcengine.com/docs/6561/1329505?lang=zh)：`seed-tts-2.0`。用于默认音色 `zh_female_vv_uranus_bigtts` 的台灯播报。

Web 配置步骤：

1. 打开 `设置 -> 模型 -> 声音和唤醒`。
2. 将 `播报服务` 设为 `火山引擎 TTS（App ID / Token）`。
3. 填写 `火山引擎 App ID` 和 `火山引擎 Access Token`。
4. 首次使用可保持默认音色 `zh_female_vv_uranus_bigtts`。
5. 如需调整音色或模型，展开 `高级：火山 TTS 音色和模型`。`TTS Model` 可选 `seed-tts-2.0-standard` / `seed-tts-2.0-expressive`；不确定时保持默认空值。
6. 点击 `保存`，然后在聊天或通话里测试语音播报。

对应配置大致如下：

```toml
[voice]
stt_provider = "volcengine"
stt_model = "bigmodel"
tts_provider = "volcengine"
tts_model = ""
tts_voice = "zh_female_vv_uranus_bigtts"
volcengine_app_id = ""
volcengine_access_token = ""
wake_word = ""
call_mode = "stable"
echo_gate_hangover_ms = 1000
echo_text_filter_enabled = true
silence_timeout_s = 60
```

唤醒词目前只支持 `Hi,小星`。保存唤醒词后，Web 会尝试把 WakeNet 模型同步到 ESP32；若固件未烧录对应模型，前端会提示错误。

## 常见配置字段

### 设备

```toml
[device]
motor_port = "/dev/ttyUSB0"
lamp_id = "AL02"
use_degrees = true
max_torque_pct = 80

[camera]
port = ""

[device_esp32]
enabled = true
preferred_host = ""
framesize = 8
jpeg_quality = 10
http_timeout_s = 5.0
```

- `motor_port`：Feetech 电机总线串口，可在 Web 硬件页保存后热重连。
- `lamp_id`：用于匹配 `assets/calibration/` 下的校准文件。
- `max_torque_pct`：电机 Torque_Limit 百分比，默认 `80`；降低堵转电流和转接板发热，不改变正常空载速度。
- `camera.port`：本地 USB 摄像头索引，如 `0` 或 `1`；使用 ESP32 摄像头时通常留空。
- `device_esp32.preferred_host`：留空表示自动发现，也可指定 `lampgo-cam-XXXX.local` 或设备 IP。

### 运动与安全

```toml
[motion]
tick_rate_hz = 50.0
default_max_velocity = 120.0
default_style = "gentle"
default_playback_mode = "cleaned"
idle_sway_enabled = true
idle_sway_idle_after_s = 600.0
idle_sway_interval_s = 30.0
idle_sway_interval_jitter_s = 8.0
idle_sway_duration_s = 8.0
idle_sway_amplitude = 6.0
idle_sway_period_s = 4.5

[safety]
max_velocity = 120.0
max_acceleration = 900.0
```

`idle_sway_*` 控制待机随机摆动：台灯空闲到 `idle_sway_idle_after_s` 后，会按 `idle_sway_interval_s ± idle_sway_interval_jitter_s` 的随机间隔触发一次出厂技能 `idle_sway`。

## 查看与修改配置

推荐方式：

```bash
uv run lampgo onboard
uv run lampgo run --web
```

然后在 Web 控制台的 `设置` 页修改配置。

手工查看：

```bash
cat ~/.lampgo/config.toml
```

仅检查字段参考：

```bash
sed -n '1,200p' lampgo.toml.example
```

## 开源发布注意事项

- 不要提交 `~/.lampgo/config.toml`、`~/.lampgo/credentials.json`、`.env`、API key、火山引擎 token 或插件 token。
- 公开 README 中尽量使用通用 provider 描述，例如 OpenAI-compatible、Anthropic-compatible、local。
- 如果项目依赖私有包源，请在发布前提供公开安装路径或将相关能力标记为可选。

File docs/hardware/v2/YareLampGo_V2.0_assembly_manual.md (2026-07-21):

# YareLampGo V2.0 组装说明（GitHub 网页版）

[下载原始 DOCX](YareLampGo_V2.0_assembly_manual.docx) · [V2.0 硬件与组装总览](README.md) · [V2.0 接线指南](../wiring.md) · [完整 STEP 总成](../../../assets/printable/YareLampGo_V2.0/YareLampGo_V2.0_assembly.step)

> 本页将原组装 DOCX 的文字和全部 42 张内嵌图片按原顺序直接整理为 Markdown，方便在 GitHub 网页端阅读。DOCX 仍保留为原始下载件。接线、电源和首次上电的安全要求以 [V2.0 硬件与组装总览](README.md) 与 [接线指南](../wiring.md) 为准。

## 一、物料清单

原 DOCX 的 1～16 项名称在表格中以图片呈现，以下保留其原始序号、数量和图片；具体零件以图片及 STEP 总成为准。

| 序号 | 数量 | 图片 |
| ---: | ---: | --- |
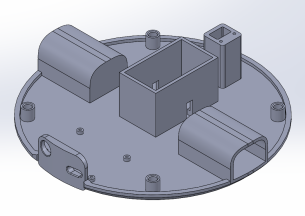
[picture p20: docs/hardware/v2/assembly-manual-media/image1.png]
物料 1
| 1 | 1 |  |
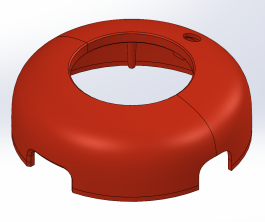
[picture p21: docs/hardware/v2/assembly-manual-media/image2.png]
物料 2
| 2 | 1 |  |
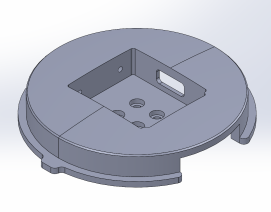
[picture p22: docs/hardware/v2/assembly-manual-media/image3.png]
物料 3
| 3 | 1 |  |
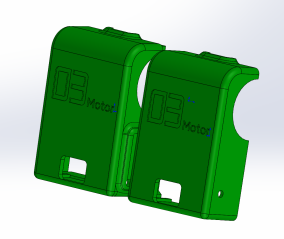
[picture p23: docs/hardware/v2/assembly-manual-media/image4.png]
物料 4
| 4 | 1 套 |  |
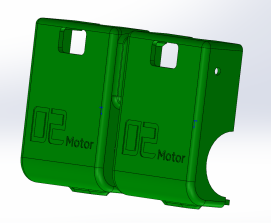
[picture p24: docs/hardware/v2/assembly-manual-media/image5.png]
物料 5
| 5 | 1 套 |  |
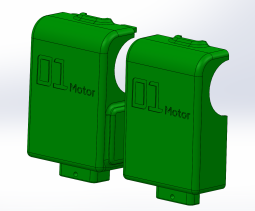
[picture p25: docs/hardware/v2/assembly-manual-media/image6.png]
物料 6
| 6 | 1 套 |  |
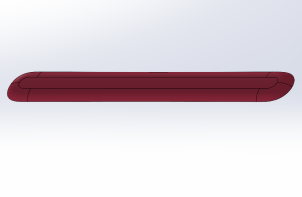
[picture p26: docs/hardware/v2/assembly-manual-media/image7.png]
物料 7
| 7 | 4 |  |
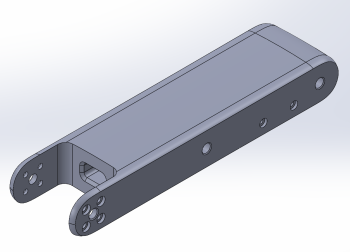
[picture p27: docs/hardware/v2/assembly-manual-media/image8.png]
物料 8
| 8 | 1 |  |
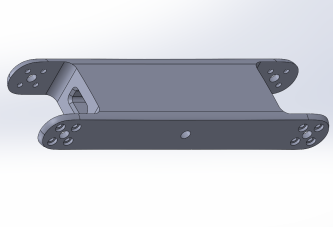
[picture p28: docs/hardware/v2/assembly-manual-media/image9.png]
物料 9
| 9 | 1 |  |
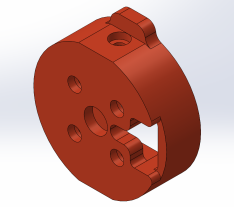
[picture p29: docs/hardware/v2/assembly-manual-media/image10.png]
物料 10
| 10 | 1 |  |
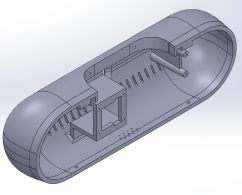
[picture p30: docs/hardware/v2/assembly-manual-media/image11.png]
物料 11
| 11 | 1 |  |
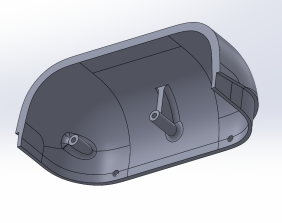
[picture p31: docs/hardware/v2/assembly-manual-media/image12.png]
物料 12
| 12 | 1 |  |
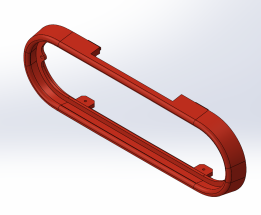
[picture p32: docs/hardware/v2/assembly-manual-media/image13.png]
物料 13
| 13 | 1 |  |
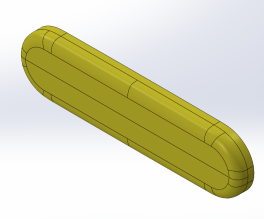
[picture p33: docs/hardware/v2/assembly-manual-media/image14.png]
物料 14
| 14 | 1 |  |
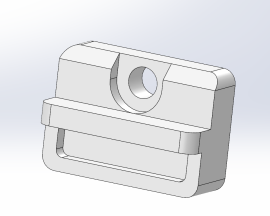
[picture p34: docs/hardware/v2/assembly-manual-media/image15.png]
物料 15
| 15 | 4 |  |
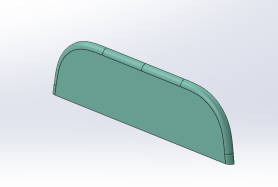
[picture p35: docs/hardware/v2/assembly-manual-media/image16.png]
物料 16
| 16 | 1 |  |
| 17 | 按需 | 螺钉 |
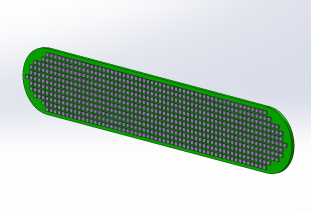
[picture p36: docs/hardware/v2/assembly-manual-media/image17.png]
LED 灯板
| 18 | 1（客供） | LED 灯板<br> |
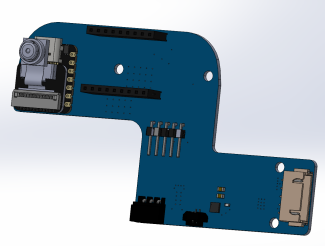
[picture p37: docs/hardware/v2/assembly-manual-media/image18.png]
控制板
| 19 | 1（客供） | 控制板<br> |
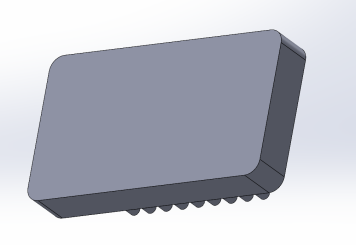
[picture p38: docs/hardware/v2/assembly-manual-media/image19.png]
显示屏幕
| 20 | 1（客供） | 显示屏幕<br> |
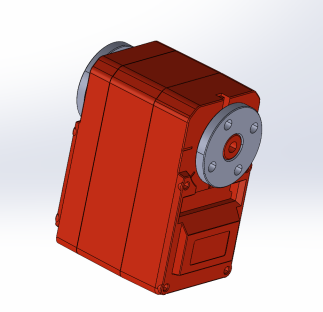
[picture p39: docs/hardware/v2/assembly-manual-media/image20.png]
舵机
| 21 | 5（客供） | 舵机<br> |
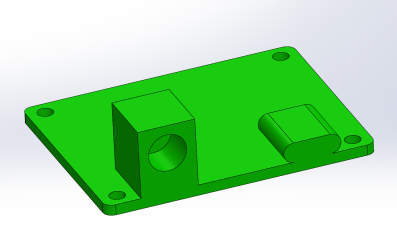
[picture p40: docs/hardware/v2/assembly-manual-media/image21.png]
电源板
| 22 | 1（客供） | 电源板<br> |
| 23 | 1（客供） | 喇叭 |

## 二、线路连接示意图

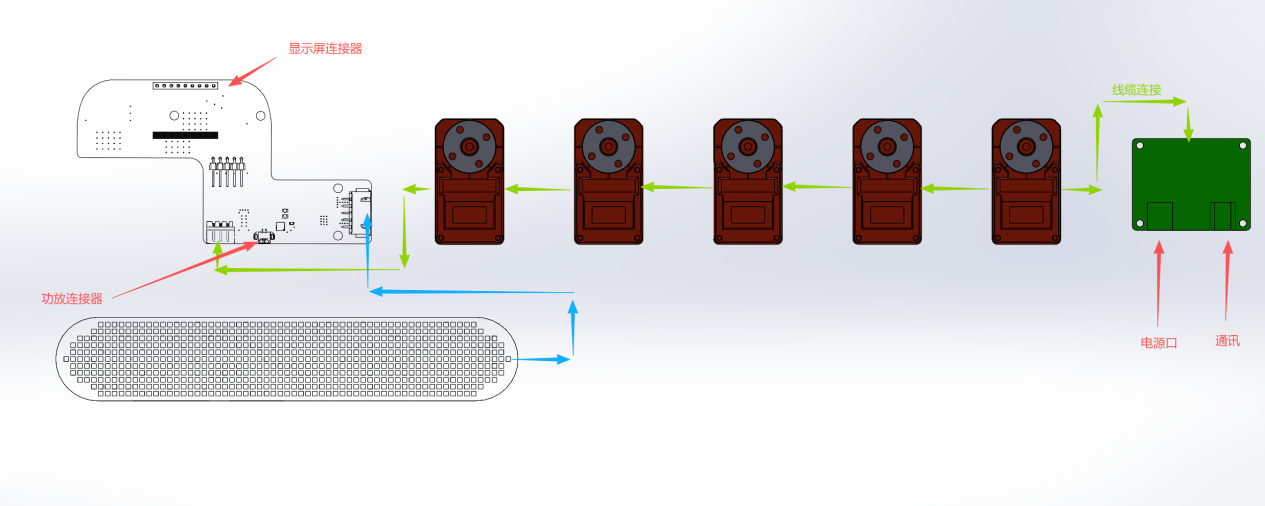
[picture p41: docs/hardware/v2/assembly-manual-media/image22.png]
DOCX 原始线路连接示意图


图中展示控制板、5 颗舵机、LED 灯板与电源板的连接关系。插接前请对照当前 [V2.0 接线指南](../wiring.md) 的网络名、接口针序和电源域；不要仅凭线色或旧版图纸接线。

## 三、加工说明

以下为原 DOCX 中的紧固件、嵌件和结构细节图。原图未给出全部紧固件长度，采购前请在 STEP 总成和实物上复核。

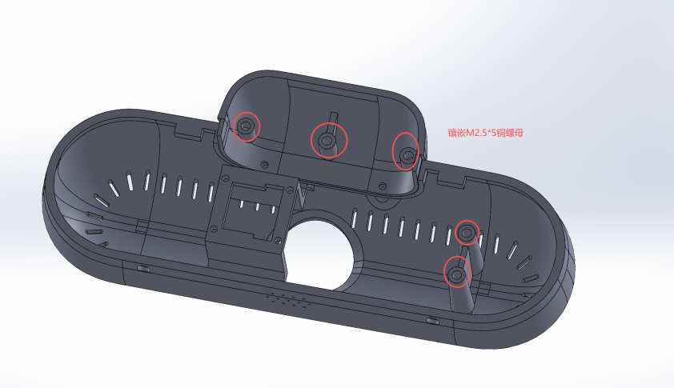
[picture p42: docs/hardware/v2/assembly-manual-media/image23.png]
加工说明 1


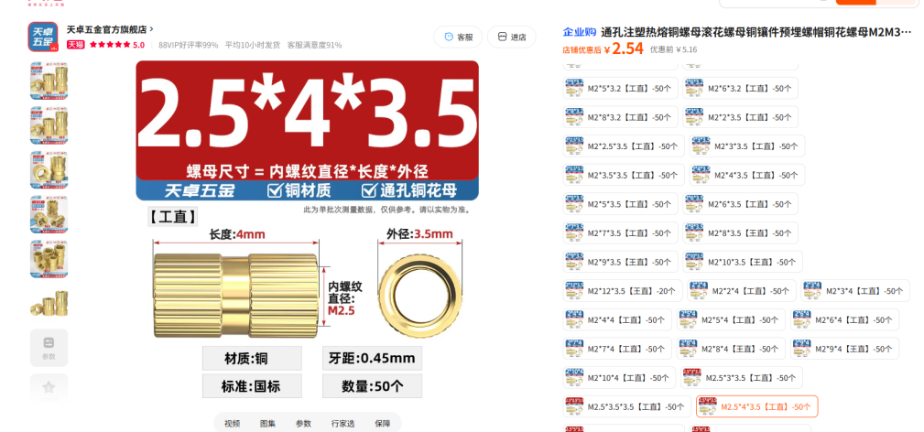
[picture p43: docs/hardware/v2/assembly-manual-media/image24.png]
加工说明 2


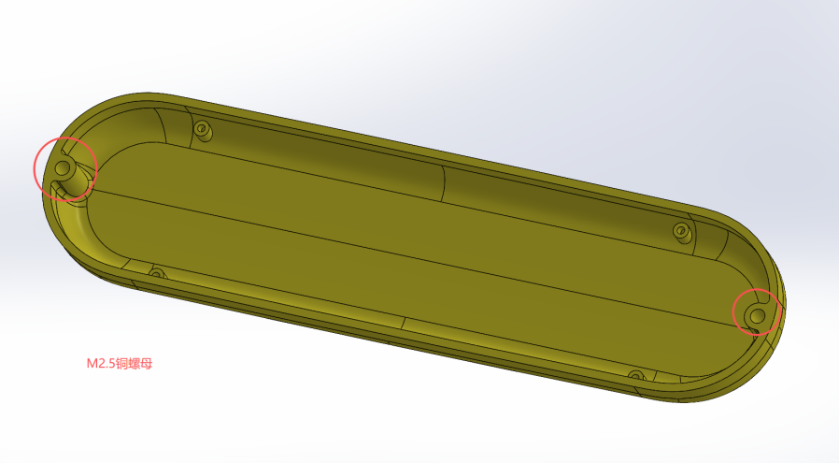
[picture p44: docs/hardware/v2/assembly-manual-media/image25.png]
加工说明 3


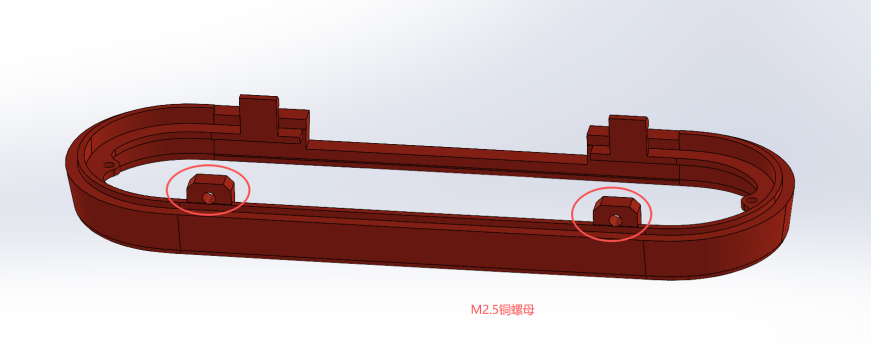
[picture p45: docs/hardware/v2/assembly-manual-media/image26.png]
加工说明 4


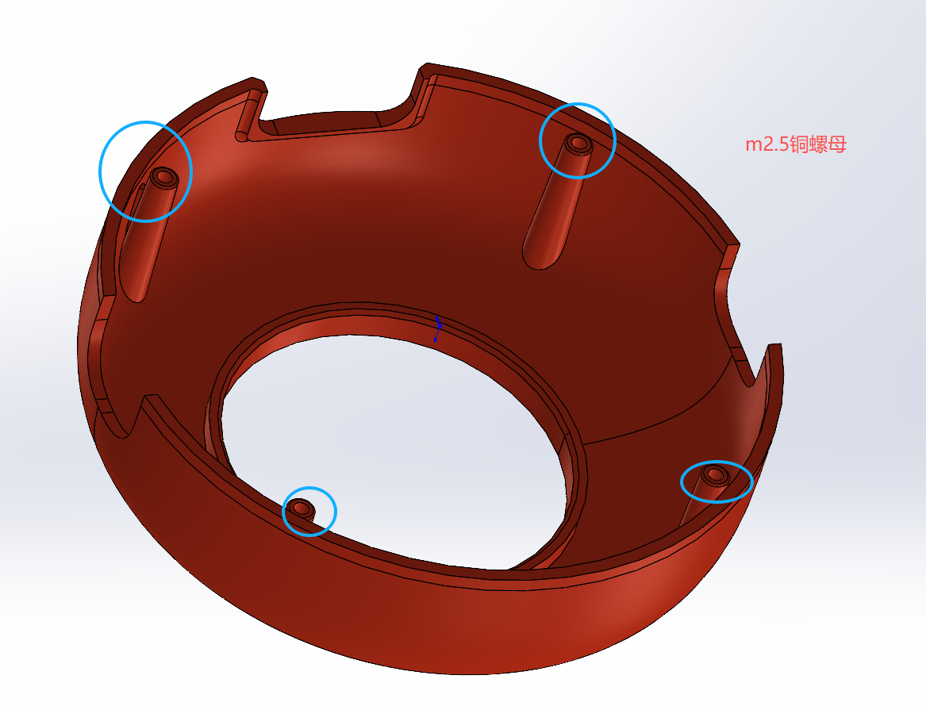
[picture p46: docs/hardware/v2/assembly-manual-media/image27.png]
加工说明 5


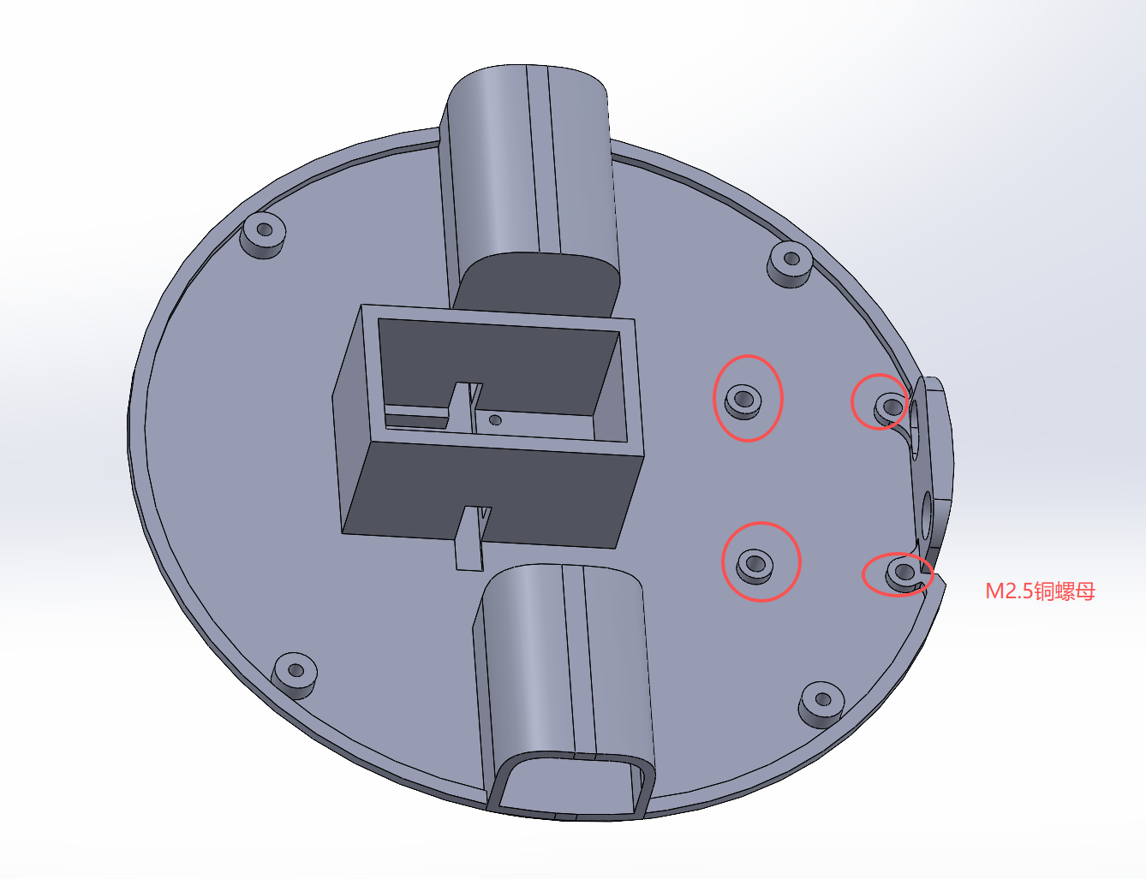
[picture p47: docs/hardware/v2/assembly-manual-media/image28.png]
加工说明 6


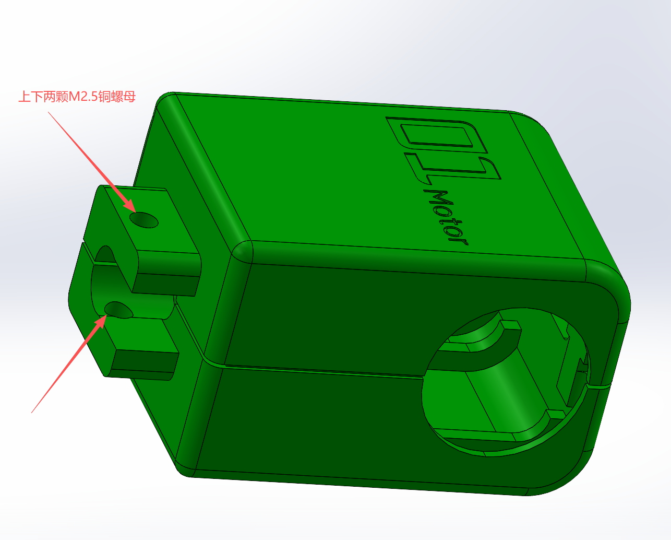
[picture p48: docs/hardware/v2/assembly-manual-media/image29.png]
加工说明 7


## 四、组装过程

### 1. 电机外壳组装

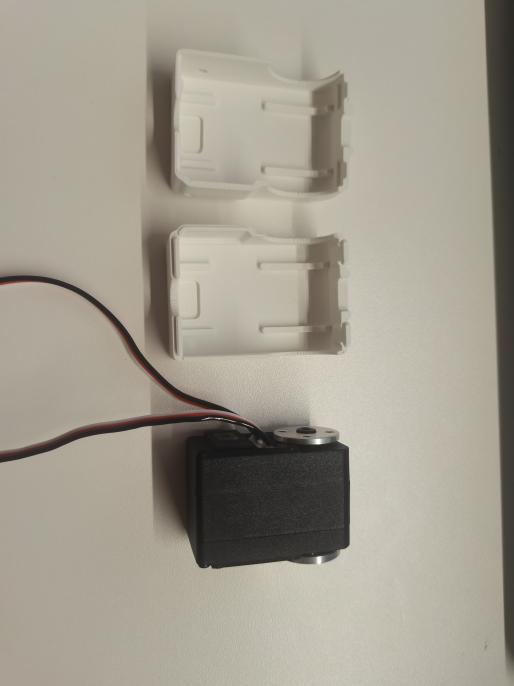
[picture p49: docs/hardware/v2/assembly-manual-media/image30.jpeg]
电机外壳组装 1


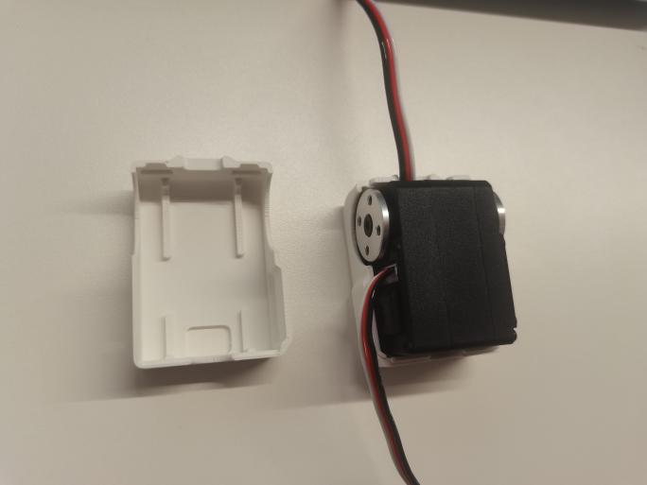
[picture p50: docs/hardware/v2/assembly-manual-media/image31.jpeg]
电机外壳组装 2


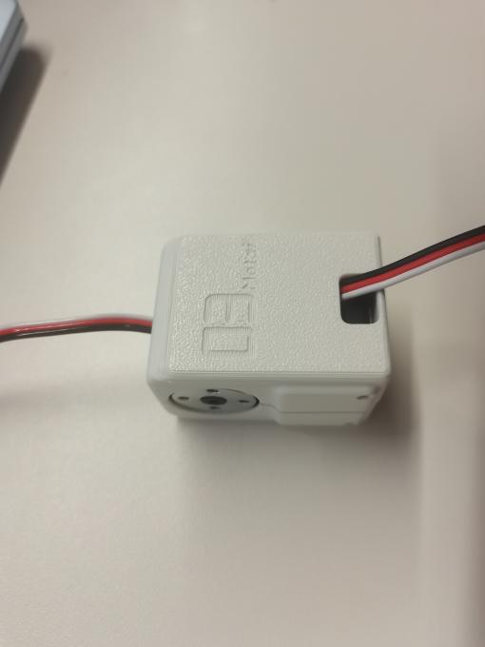
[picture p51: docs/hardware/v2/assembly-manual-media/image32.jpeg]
电机外壳组装 3


- 舵机线缆应置于外壳内部，避免被挤压导致外壳无法完全装到位。
- 三处舵机的线缆走向保持一致。
- 写入舵机 ID 或更换线缆前必须断开 12V；写 ID 时总线上只能连接一颗未编号舵机。具体 ID 对应关系见 [V2.0 接线指南](../wiring.md)。

### 2. 底座与支架组装

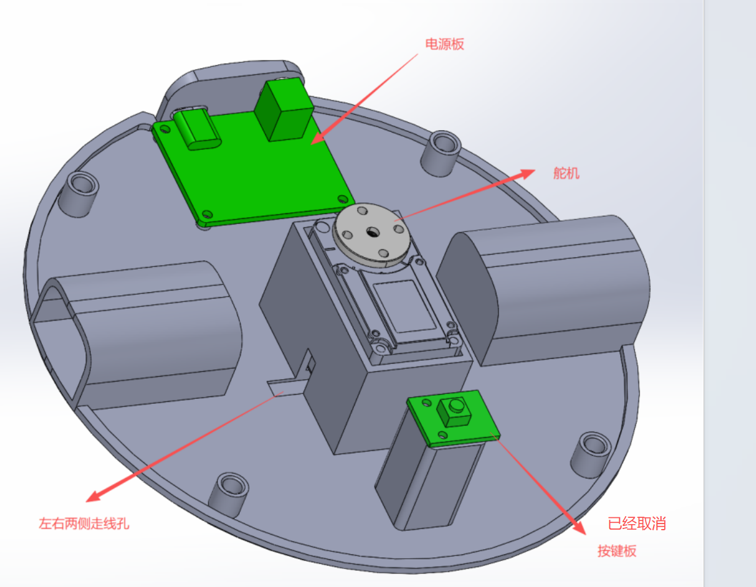
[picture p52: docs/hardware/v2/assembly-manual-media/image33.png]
底座与支架布局


安装位置如图：使用自攻螺钉固定；舵机从底部以四颗自攻螺钉固定。

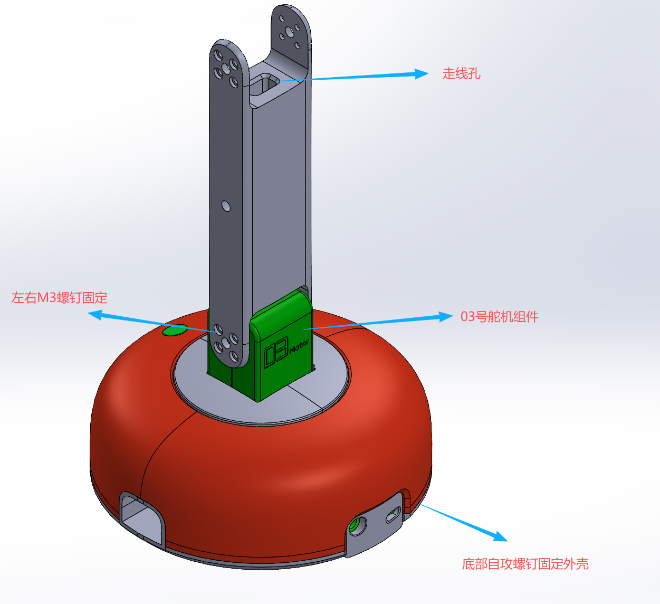
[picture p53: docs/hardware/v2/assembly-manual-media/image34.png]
底座与支架步骤 1


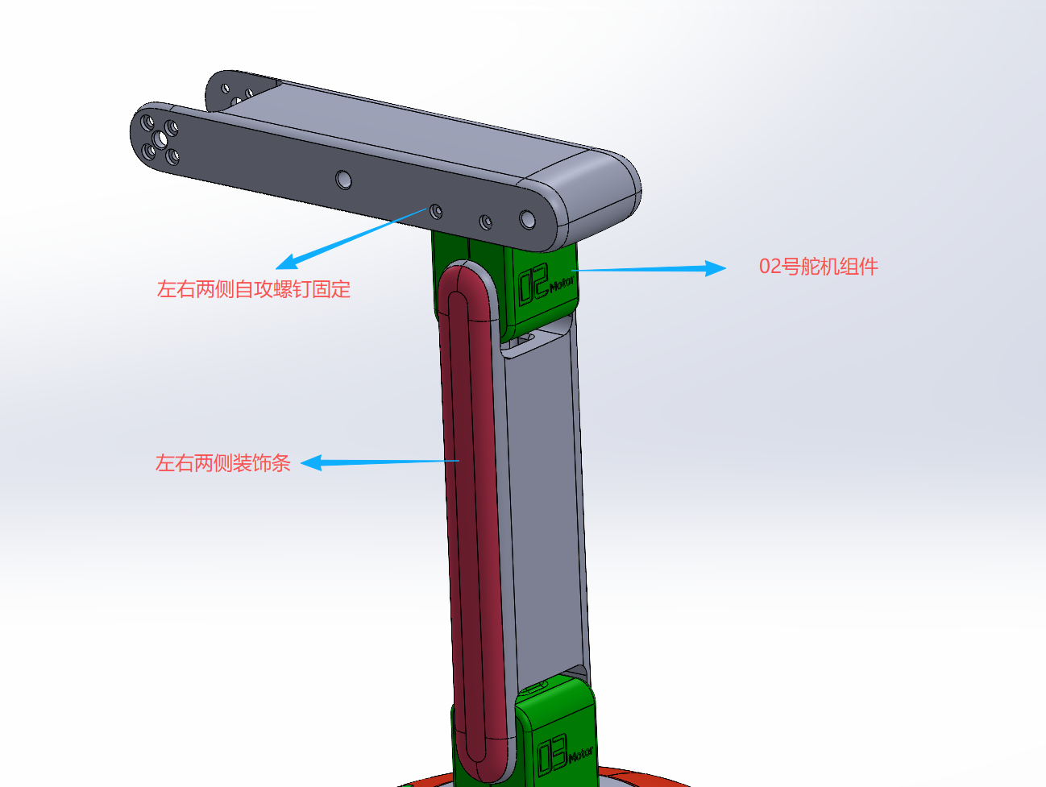
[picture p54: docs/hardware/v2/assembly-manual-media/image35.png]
底座与支架步骤 2


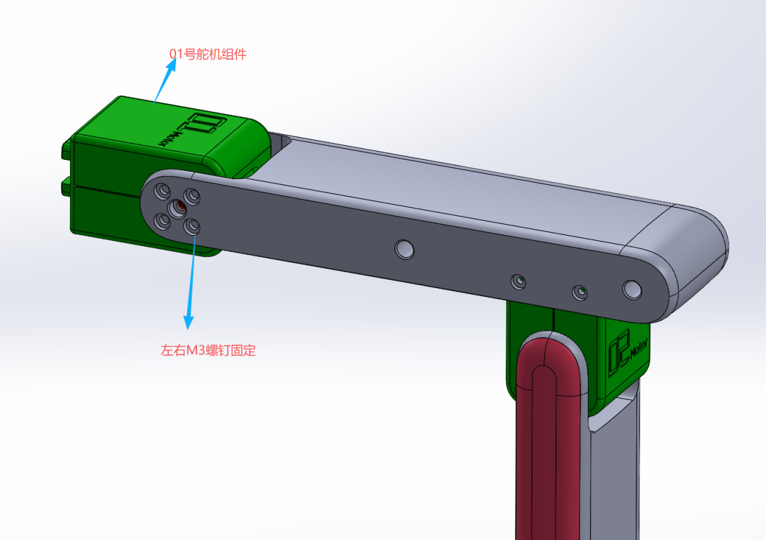
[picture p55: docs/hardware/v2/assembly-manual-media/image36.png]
底座与支架步骤 3


完成机械结构前，确认线束已穿过指定走线孔，并在关节全行程内不会被拉扯、磨损或夹住。

### 3. 灯头组装

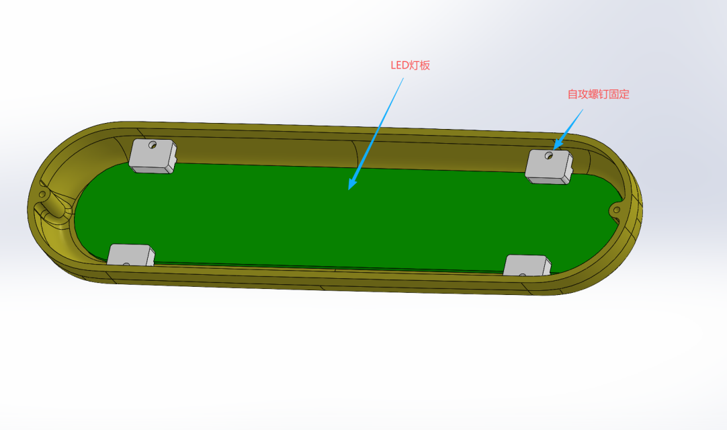
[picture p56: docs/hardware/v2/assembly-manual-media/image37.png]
灯头步骤 1


灯头步骤 2

灯头步骤 3

灯头步骤 4

灯头步骤 5

安装 LED、屏幕、控制板、喇叭与外壳前后，均应对照 [V2.0 接线指南](../wiring.md) 核对 +5V/GND、S3/C6 UART 方向和 LED U3 针序。新板首次上电前，先移除 S3、C6、LED 和功放，确认电源板 +5V 对 GND 正确后再装回逻辑模块。

## 五、成品展示

YareLampGo V2.0 成品展示

## 首次上电前必查

原 DOCX 是机械组装参考；首次上电前请额外完成以下 V2.0 检查：

1. 不混用 V1/V2 结构件、接线图或校准文件。
2. 确认 12V 舵机侧和 +5V 逻辑侧没有接反，所有逻辑地共地。
3. S3 GPIO43 TX → C6 RX，S3 GPIO44 RX ← C6 TX；LED U3 针序以 PCB 丝印和实测方向为准。
4. 扶稳机构、清空运动范围后，先运行 `uv run lampgo detect`、`uv run lampgo scan-motors --ids 1-5` 和 `uv run lampgo ping`，确认五颗舵机稳定在线后再校准。

完整手动软件、烧录与校准流程见 [V2.0 手动安装、烧录与首次启动](../../getting-started/manual-hardware-setup.md)。

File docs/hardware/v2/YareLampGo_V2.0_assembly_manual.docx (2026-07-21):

台灯2.0版本清单及组装指导说明

一、物料清单：

序号 | 名称 | 图片 | 数量 | 材质 | 备注
| | | 1
| | | 1
| | | 1
| | | 1/套
| | | 1/套
| | | 1/套
| | | 4
| | | 1


| | | 1
| | | 1
| | | 1
| | | 1
| | | 1
| | | 1
| | | 4
| | | 1
| 螺钉 | | 按需
| LED灯板 | | 1 | | 客供
| 控制板 | | 1 | | 客供


| 显示屏幕 | | 1 | | 客供
| 舵机 | | 5 | | 客供


| 电源板 | | 1 | | 客供
| 喇叭 | | 1 | | 客供

二、线路连接示意图


3、 加工说明


3、 组装过程：
1、 电机外壳组装

微信图片_20260702135341_8_96
微信图片_20260702135340_7_96
微信图片_20260702135338_6_96

注意点：1、舵机线缆置于外壳内部中，避免线缆得挤压，导致外壳无法安装到位；

2、三处舵机得线缆走向一致。

2、底座与支架的组装过程


安装位置布局如上图：使用自攻螺钉固定。舵机通过底部得四颗自攻螺钉固定。


3、灯头的组装


成品展示：


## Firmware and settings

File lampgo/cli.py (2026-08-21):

"""lampgo CLI — the user-facing command-line interface.

Usage:
    lampgo run [--motor-port PORT] [--web]
    lampgo invoke <skill_id> [key=value ...]
    lampgo text "做个害羞的表情"
    lampgo move base_yaw=30 base_pitch=-20
    lampgo play nod
    lampgo skills
    lampgo status
    lampgo detect
    lampgo estop
    lampgo calibrate
    lampgo record my_action

Commands that talk to the daemon (invoke, text, status, skills, estop)
use local IPC for <100ms latency (Unix socket on POSIX, loopback TCP on Windows).

Commands that need standalone hardware access (move, play, calibrate, record)
try IPC first, then fall back to creating their own server instance.
"""

from __future__ import annotations

import argparse
import asyncio
import json
import os
import signal
import subprocess
import sys
import time
from pathlib import Path

import structlog

structlog.configure(
    processors=[
        structlog.dev.ConsoleRenderer(),
    ],
    wrapper_class=structlog.make_filtering_bound_logger(20),
)

logger = structlog.get_logger(__name__)


def _configure_windows_console_encoding() -> None:
    """Keep Windows CLI output printable when the active console is not UTF-8."""
    if os.name != "nt":
        return
    for stream in (sys.stdout, sys.stderr):
        reconfigure = getattr(stream, "reconfigure", None)
        if reconfigure is None:
            continue
        try:
            reconfigure(encoding="utf-8", errors="replace")
        except (AttributeError, OSError, ValueError):
            continue


def main() -> None:
    _configure_windows_console_encoding()
    parser = argparse.ArgumentParser(
        prog="lampgo",
        description="lampgo — intelligent lamp robot runtime",
        epilog="Config: ~/.lampgo/config.toml (run `lampgo onboard` to configure; Web UI to edit)",
    )
    parser.add_argument("--config", default=None, help="[deprecated] Ignored; kept for compatibility")
    sub = parser.add_subparsers(dest="command")

    # --- run (start daemon) ---
    run_p = sub.add_parser("run", help="Start the lampgo daemon")
    run_p.add_argument("--motor-port", default=None, help="Serial port for motor bus (overrides config)")
    run_p.add_argument("--led-port", default=None, help="Serial port for ESP32 LEDs (overrides config)")
    run_p.add_argument("--lamp-id", default=None, help="Lamp identity for calibration")
    run_p.add_argument("--recordings-dir", default=None, help="Path to recording CSVs")
    run_p.add_argument("--web", action="store_true", help="Enable web UI (chat interface)")
    run_p.add_argument("--web-port", type=int, default=None, help="Web UI port (default: 8420)")
    run_p.add_argument("--no-home", action="store_true", help="Skip automatic homing on startup")
    run_p.add_argument("--no-hw", action="store_true", help="Skip hardware (motors/LED) — web only")

    # --- invoke (IPC) ---
    inv_p = sub.add_parser("invoke", help="Invoke a skill on the running daemon")
    inv_p.add_argument("skill_id", help="Skill ID to invoke")
    inv_p.add_argument("params", nargs="*", help="Parameters: key=value ...")

    # --- text (IPC) ---
    txt_p = sub.add_parser("text", help="Send free text through the intent router")
    txt_p.add_argument("input", help="Text input (e.g. '做个害羞的表情')")

    # --- status (IPC) ---
    sub.add_parser("status", help="Query daemon status")

    # --- skills (local or IPC) ---
    sub.add_parser("skills", help="List available skills")

    # --- detect ---
    sub.add_parser("detect", help="Auto-detect serial ports")

    # --- estop (IPC) ---
    sub.add_parser("estop", help="Emergency stop (sends to daemon)")

    # --- move (IPC or standalone) ---
    move_p = sub.add_parser("move", help="Move joints (e.g. base_yaw=30 base_pitch=-20)")
    move_p.add_argument("joints", nargs="+", help="Joint assignments: name=value")
    move_p.add_argument("--motor-port", default=None)
    move_p.add_argument("--velocity", type=float, default=None)

    # --- play (IPC or standalone) ---
    play_p = sub.add_parser("play", help="Play a recording")
    play_p.add_argument("name", help="Recording name")
    play_p.add_argument("--motor-port", default=None)
    play_p.add_argument("--recordings-dir", default=None)
    play_p.add_argument("--fps", type=int, default=0)

    # --- calibrate ---
    cal_p = sub.add_parser("calibrate", help="Run interactive motor calibration")
    cal_p.add_argument("--id", default=None, help="Lamp ID (default: from config)")
    cal_p.add_argument("--port", default=None, help="Serial port (default: config, then auto-detect)")
    cal_p.add_argument(
        "--auto-detect",
        "--rescan",
        dest="auto_detect",
        action="store_true",
        help="Ignore the saved motor port and rescan serial ports",
    )

    # --- record ---
    rec_p = sub.add_parser("record", help="Record a teach action (torque off, move arm manually)")
    rec_p.add_argument("name", help="Name for the recording")
    rec_p.add_argument("--motor-port", default=None)
    rec_p.add_argument("--recordings-dir", default=None)
    rec_p.add_argument("--fps", type=int, default=30)

    # --- clear ---
    clear_p = sub.add_parser("clear", help="Stop related processes and release motor torque")
    clear_p.add_argument(
        "--skip-kill",
        action="store_true",
        help="Do not terminate related processes; also skip torque release",
    )
    clear_p.add_argument("--skip-release", action="store_true", help="Do not connect/disconnect motor bus")

    # --- ping ---
    ping_p = sub.add_parser("ping", help="Ping all motor IDs and report status")
    ping_p.add_argument("--port", default=None, help="Serial port (default: config, then auto-detect)")
    ping_p.add_argument(
        "--auto-detect",
        "--rescan",
        dest="auto_detect",
        action="store_true",
        help="Ignore the saved motor port and rescan serial ports",
    )

    # --- setup-motors ---
    setup_p = sub.add_parser("setup-motors", help="Interactively assign Feetech motor IDs")
    setup_p.add_argument("--port", default=None, help="Serial port (default: config, then auto-detect)")
    setup_p.add_argument(
        "--auto-detect",
        "--rescan",
        dest="auto_detect",
        action="store_true",
        help="Ignore the saved motor port and rescan serial ports",
    )

    # --- scan-motors ---
    scan_p = sub.add_parser(
        "scan-motors",
        help="Raw bus scan: probe ID 1-253 with bare pyserial, bypassing lerobot model checks. "
             "Use for hardware diagnosis when calibrate/ping find nothing.",
    )
    scan_p.add_argument("--port", default=None, help="Serial port (default: config, then auto-detect)")
    scan_p.add_argument(
        "--auto-detect",
        "--rescan",
        dest="auto_detect",
        action="store_true",
        help="Ignore the saved motor port and rescan serial ports",
    )
    scan_p.add_argument(
        "--baud", type=int, default=1_000_000, help="Baud rate (default: 1000000)"
    )
    scan_p.add_argument(
        "--ids",
        default="1-20",
        help="ID range or list to probe, e.g. '1-20' or '1,3,5' (default: 1-20)",
    )
    scan_p.add_argument(
        "--timeout", type=float, default=0.1, help="Per-ID read timeout in seconds (default: 0.1)"
    )

    # Internal stdio MCP entrypoint. Codex starts this automatically after
    # LampGo registers the integration; users should not need to run it.
    sub.add_parser("mcp-stdio", help="Internal Codex bridge (started automatically)")

    # --- guided onboarding ---
    # Primary name is `onboard`. We also register `install` as a hidden alias so
    # any old docs / muscle memory still works for a while.
    inst_p = sub.add_parser(
        "onboard",
        aliases=["install"],
        help="Guided first-run setup: hardware, LLM, persona, Codex integration",
    )
    inst_p.add_argument(
        "--non-interactive",
        action="store_true",
        help="Take defaults for every prompt (useful for scripts / CI).",
    )
    inst_p.add_argument("--yes", "-y", action="store_true", help="Answer yes to confirmations.")
    inst_p.add_argument(
        "--skip",
        default="",
        help="Comma-separated step names to skip "
        "(env_check, audio_tap, hardware, llm, persona_memory, codex).",
    )
    inst_p.add_argument("--motor-port", default=None, help="Preset motor serial port for the hardware step.")
    inst_p.add_argument("--llm-provider", default=None, help="Preset LLM provider for the llm step.")
    inst_p.add_argument("--llm-key", default=None, help="Preset LLM API key for the llm step.")

    # --- help ---
    sub.add_parser("help", help="Show quick manual debugging commands")

    args = parser.parse_args()
    if args.command is None:
        parser.print_help()
        sys.exit(0)

    dispatch = {
        "run": _cmd_run,
        "invoke": _cmd_invoke,
        "text": _cmd_text,
        "status": _cmd_status,
        "skills": _cmd_skills,
        "detect": _cmd_detect,
        "estop": _cmd_estop,
        "move": _cmd_move,
        "play": _cmd_play,
        "calibrate": _cmd_calibrate,
        "record": _cmd_record,
        "clear": _cmd_clear,
        "ping": _cmd_ping,
        "setup-motors": _cmd_setup_motors,
        "scan-motors": _cmd_scan_motors,
        "mcp-stdio": _cmd_mcp_stdio,
        "onboard": _cmd_onboard,
        "install": _cmd_onboard,
        "help": _cmd_help,
    }
    handler = dispatch.get(args.command)
    if handler:
        handler(args)
    else:
        parser.print_help()


# ---------------------------------------------------------------------------
# IPC helpers
# ---------------------------------------------------------------------------


def _ipc_or_die(request: dict) -> dict:
    """Send IPC request; exit with helpful message if daemon is not running."""
    from lampgo.ipc import ipc_send

    try:
        return ipc_send(request)
    except (ConnectionRefusedError, FileNotFoundError, OSError):
        print(
            "Error: lampgo daemon is not running.\n"
            "Start it with: lampgo run\n"
            "Or use --motor-port for standalone mode.",
            file=sys.stderr,
        )
        sys.exit(1)


def _parse_kv_params(pairs: list[str]) -> dict:
    params: dict = {}
    for pair in pairs:
        if "=" not in pair:
            print(f"Invalid parameter: {pair}  (expected key=value)", file=sys.stderr)
            sys.exit(1)
        key, val = pair.split("=", 1)
        try:
            params[key.strip()] = float(val.strip())
        except ValueError:
            params[key.strip()] = val.strip()
    return params


# ---------------------------------------------------------------------------
# IPC-based commands (talk to running daemon)
# ---------------------------------------------------------------------------


def _cmd_invoke(args: argparse.Namespace) -> None:
    params = _parse_kv_params(args.params) if args.params else {}
    result = _ipc_or_die({"cmd": "invoke", "skill_id": args.skill_id, "params": params})
    print(json.dumps(result, ensure_ascii=False, indent=2))


def _cmd_text(args: argparse.Namespace) -> None:
    result = _ipc_or_die({"cmd": "text", "input": args.input})
    print(json.dumps(result, ensure_ascii=False, indent=2))


def _cmd_status(args: argparse.Namespace) -> None:
    result = _ipc_or_die({"cmd": "status"})
    print(json.dumps(result, ensure_ascii=False, indent=2))


def _cmd_estop(args: argparse.Namespace) -> None:
    result = _ipc_or_die({"cmd": "estop"})
    print("E-STOP sent.")
    print(json.dumps(result, ensure_ascii=False, indent=2))


def _build_help_text() -> str:
    return (
        "YareLampGo 常用 CLI\n"
        "===================\n\n"
        "最常用的 4 个命令\n"
        "  uv run lampgo help                 # 打开本速查页\n"
        "  uv run lampgo detect               # 发现串口、摄像头和 ESP32\n"
        "  uv run lampgo calibrate            # 交互式校准 5 个关节\n"
        "  uv run lampgo run --web            # 启动台灯和 Web 控制台\n\n"
        "1) 第一次安装与配置\n"
        "  uv run lampgo onboard              # 配置硬件、LLM、人设和 Codex\n"
        "  uv run lampgo onboard -y --skip persona_memory,codex\n"
        "                                      # 接受默认值，并跳过指定步骤\n\n"
        "2) 发现设备与诊断舵机总线\n"
        "  uv run lampgo detect               # 只读发现串口/摄像头/网络设备\n"
        "  uv run lampgo scan-motors --ids 1-5\n"
        "                                      # 默认自动选择电机 COM 并扫描 V2 的 5 个舵机 ID\n"
        "  uv run lampgo scan-motors --auto-detect --ids 1-5\n"
        "                                      # 忽略旧配置并强制重扫 COM\n"
        "  uv run lampgo scan-motors --port COM5 --ids 1-20\n"
        "                                      # 多串口时显式指定电机适配器\n"
        "  uv run lampgo ping --auto-detect   # 自动重扫并读取舵机状态\n\n"
        "3) 启动、查看状态与退出\n"
        "  uv run lampgo run --web            # 真实硬件；浏览器打开 http://127.0.0.1:8420\n"
        "  uv run lampgo run --web --no-hw    # 无硬件体验 Web/Agent/配置\n"
        "  uv run lampgo run --web --web-port 8421\n"
        "                                      # 修改 Web 端口\n"
        "  uv run lampgo status               # 查询正在运行的 daemon\n"
        "  uv run lampgo skills               # 列出可调用的技能\n"
        "  Ctrl+C                              # 优雅停止 daemon\n\n"
        "4) 调用技能、文本路由与小幅动作\n"
        "  uv run lampgo text \"做个害羞的表情\"\n"
        "                                      # 让意图路由器处理自然语言\n"
        "  uv run lampgo invoke set_expression expression=heart\n"
        "                                      # 按 skill ID 直接调用并传 key=value\n"
        "  uv run lampgo move base_yaw=5 --velocity 20\n"
        "                                      # 校准后再做小角度、低速度测试\n"
        "  uv run lampgo invoke return_safe    # 回到安全位\n\n"
        "5) 舵机编号与校准（会改变硬件状态）\n"
        "  uv run lampgo setup-motors         # 默认自动检测 COM 口\n"
        "  uv run lampgo setup-motors --auto-detect\n"
        "                                      # 忽略旧配置并重新扫描 COM 口\n"
        "  uv run lampgo setup-motors --port COM5\n"
        "                                      # 多串口且无法唯一识别时手动确认\n"
        "  uv run lampgo calibrate --auto-detect --id AL02\n"
        "                                      # 自动选择电机口并从仓库根目录校准\n\n"
        "6) 录制与回放动作\n"
        "  uv run lampgo record my_action --fps 30\n"
        "                                      # 释放扭矩后手动示教，Ctrl+C 结束\n"
        "  uv run lampgo play my_action        # 回放已保存动作\n\n"
        "7) 安全与恢复\n"
        "  uv run lampgo estop                 # 向运行中的 daemon 发送急停\n"
        "  uv run lampgo clear                 # 停止相关进程并尝试释放电机扭矩\n\n"
        "更多参数\n"
        "  uv run lampgo --help\n"
        "  uv run lampgo <command> --help      # 例如 uv run lampgo run --help\n\n"
        "注意：舵机写 ID、校准和首次真实运动前先清空运动范围并准备断开 12V。\n"
        "需要独占串口的调试命令不要和 lampgo run 同时操作同一条电机总线。"
    )


def _find_related_pids() -> list[int]:
    """Find LampGo process ids, excluding the current command and its parent."""
    if os.name == "nt":
        return _find_related_pids_windows()
    return _find_related_pids_posix()


def _find_related_pids_posix() -> list[int]:
    """Find LampGo processes from the POSIX process table."""

    current_pid = os.getpid()
    parent_pid = os.getppid()
    try:
        result = subprocess.run(
            ["ps", "-axo", "pid=,command="],
            capture_output=True,
            text=True,
            check=False,
        )
    except OSError:
        return []
    markers = (
        "lampgo run",
        "lampgo invoke",
        "lampgo move",
        "lampgo play",
    )
    pids: list[int] = []
    for line in result.stdout.splitlines():
        line = line.strip()
        if not line:
            continue
        parts = line.split(maxsplit=1)
        if len(parts) < 2:
            continue
        try:
            pid = int(parts[0])
        except ValueError:
            continue
        cmd = parts[1]
        if pid in (current_pid, parent_pid):
            continue
        if any(marker in cmd for marker in markers):
            pids.append(pid)
    return sorted(set(pids))


def _find_related_pids_windows() -> list[int]:
    """Find LampGo processes through psutil on Windows."""
    psutil = _load_windows_psutil()
    if psutil is None:
        return []

    current_pid = os.getpid()
    parent_pid = os.getppid()
    markers = (
        "lampgo run",
        "lampgo invoke",
        "lampgo move",
        "lampgo play",
        "lampgo.exe run",
        "lampgo.exe invoke",
        "lampgo.exe move",
        "lampgo.exe play",
    )
    pids: list[int] = []
    for process in psutil.process_iter(["pid", "cmdline"]):
        try:
            pid = int(process.info.get("pid", process.pid))
            command = process.info.get("cmdline") or []
            if isinstance(command, str):
                text = command.casefold()
            else:
                text = " ".join(str(item) for item in command).casefold()
        except (AttributeError, KeyError, TypeError, ValueError, psutil.Error):
            continue
        if pid in (current_pid, parent_pid):
            continue
        if any(marker in text for marker in markers):
            pids.append(pid)
    return sorted(set(pids))


def _load_windows_psutil():
    """Return psutil for Windows cleanup, or warn once per attempted operation."""
    try:
        import psutil
    except ImportError:
        print(
            "[warn] Windows process cleanup requires psutil. "
            "Re-run .\\install.ps1 or install the project dependencies.",
            file=sys.stderr,
        )
        return None
    return psutil


def _terminate_pids(pids: list[int]) -> tuple[list[int], list[int]]:
    """Stop related processes and return confirmed-stopped and failed PIDs."""
    if os.name == "nt":
        return _terminate_pids_windows(pids)

    targets = sorted(set(pids))
    failed: set[int] = set()
    for pid in targets:
        try:
            os.kill(pid, signal.SIGTERM)
        except ProcessLookupError:
            pass
        except Exception:
            failed.add(pid)

    remaining = _wait_for_posix_pids(
        [pid for pid in targets if pid not in failed],
        timeout_s=1.0,
    )
    for pid in remaining:
        try:
            os.kill(pid, signal.SIGKILL)
        except ProcessLookupError:
            pass
        except Exception:
            failed.add(pid)

    failed.update(
        _wait_for_posix_pids(
            [pid for pid in remaining if pid not in failed],
            timeout_s=1.0,
        )
    )
    stopped = [pid for pid in targets if pid not in failed]
    return stopped, sorted(failed)


def _wait_for_posix_pids(pids: list[int], timeout_s: float) -> list[int]:
    """Wait for POSIX PIDs to disappear and return any still present."""
    remaining = set(pids)
    deadline = time.monotonic() + timeout_s
    while remaining:
        alive: set[int] = set()
        for pid in remaining:
            try:
                os.kill(pid, 0)
            except ProcessLookupError:
                continue
            except OSError:
                alive.add(pid)
            else:
                alive.add(pid)
        remaining = alive
        if not remaining or time.monotonic() >= deadline:
            break
        time.sleep(0.05)
    return sorted(remaining)


def _terminate_pids_windows(pids: list[int]) -> tuple[list[int], list[int]]:
    """Stop Windows processes, waiting after graceful and forced termination."""
    psutil = _load_windows_psutil()
    if psutil is None:
        return [], sorted(set(pids))

    targets = sorted(set(pids))
    failed: set[int] = set()
    processes = []
    for pid in targets:
        try:
            process = psutil.Process(pid)
            process.terminate()
            processes.append(process)
        except psutil.NoSuchProcess:
            pass
        except (psutil.AccessDenied, OSError):
            failed.add(pid)

    if processes:
        _, alive = psutil.wait_procs(processes, timeout=1.0)
        for process in alive:
            try:
                process.kill()
            except psutil.NoSuchProcess:
                pass
            except (psutil.AccessDenied, OSError):
                failed.add(process.pid)
        _, still_alive = psutil.wait_procs(alive, timeout=1.0)
        failed.update(process.pid for process in still_alive)

    stopped = [pid for pid in targets if pid not in failed]
    return stopped, sorted(failed)


def _release_motor_torque(config) -> str:
    """Connect and disconnect once to release torque cleanly."""
    from lampgo.core.config import DeviceConfig
    from lampgo.core.hal import HardwareAbstraction

    port = config.device.motor_port
    if not port:
        return "Skipped torque release: motor_port not configured."

    try:
        hal = HardwareAbstraction(DeviceConfig(motor_port=port, lamp_id=config.device.lamp_id))
        hal.connect(calibrate=False)
        hal.disconnect()
        return f"Torque release done on {port}."
    except Exception as e:
        return f"Torque release failed on {port}: {e}"
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

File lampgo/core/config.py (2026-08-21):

"""Configuration models for lampgo.

Config loading priority (highest wins):
  1. CLI arguments
  2. Shell environment variables (LAMPGO_MOTOR_PORT, etc.)
  3. .env file in project root (loaded as environment variables)
  4. ~/.lampgo/credentials.json (LLM API keys)
  5. ~/.lampgo/config.toml (written by `lampgo onboard` + Web UI)
  6. Built-in defaults

Note: the legacy ``./lampgo.toml`` in the repo root is no longer read.
Run ``lampgo onboard`` to migrate any values in it to ``~/.lampgo/config.toml``.
``lampgo.toml.example`` is kept purely as field-reference documentation.
"""

from __future__ import annotations

import os
from pathlib import Path
from typing import Any, ClassVar, Literal

from dotenv import load_dotenv
from pydantic import BaseModel, Field, field_validator

from lampgo.ipc import DEFAULT_SOCKET_PATH, DEFAULT_TCP_HOST, DEFAULT_TCP_PORT


class JointLimits(BaseModel):
    """Position limits for a single joint (degrees)."""

    min: float
    max: float


DEFAULT_JOINT_LIMITS: dict[str, JointLimits] = {
    "base_yaw": JointLimits(min=-150.0, max=150.0),
    "base_pitch": JointLimits(min=-100.0, max=65.0),
    "elbow_pitch": JointLimits(min=-90.0, max=100.0),
    "wrist_roll": JointLimits(min=-75.0, max=75.0),
    "wrist_pitch": JointLimits(min=-45.0, max=100.0),
}


def _default_socket_path() -> str:
    """Return the platform-native local IPC endpoint setting."""
    if os.name == "nt":
        return f"tcp://{DEFAULT_TCP_HOST}:{DEFAULT_TCP_PORT}"
    return DEFAULT_SOCKET_PATH


class MotorConfig(BaseModel):
    """Per-motor hardware configuration."""

    id: int
    model: str = "sts3215"


DEFAULT_MOTORS: dict[str, MotorConfig] = {
    "base_yaw": MotorConfig(id=1),
    "base_pitch": MotorConfig(id=2),
    "elbow_pitch": MotorConfig(id=3),
    "wrist_roll": MotorConfig(id=4),
    "wrist_pitch": MotorConfig(id=5),
}


class DeviceConfig(BaseModel):
    """Hardware connection settings."""

    motor_port: str = Field(default="", description="Serial port for the Feetech motor bus, e.g. /dev/ttyUSB0")
    led_port: str = Field(default="", description="Serial port for ESP32 LED controller (empty = disabled)")
    lamp_id: str = Field(default="AL02", description="Device identity used for calibration file lookup")
    motors: dict[str, MotorConfig] = Field(default_factory=lambda: dict(DEFAULT_MOTORS))
    use_degrees: bool = Field(default=True, description="Interpret positions as degrees (vs normalised -100..100)")
    disable_torque_on_disconnect: bool = True
    calibration_dir: Path = Field(default=Path("assets/calibration"))
    max_torque_pct: int = Field(
        default=80,
        ge=10,
        le=100,
        description=(
            "Maximum torque limit as a percentage of rated torque (10-100). "
            "Applied to every motor at startup via the Torque_Limit register. "
            "Only affects stall current (motor jammed against a hard stop); "
            "free-running speed and acceleration are unaffected up to this limit. "
            "80% cuts worst-case stall current by ~20%% while preserving full "
            "expressiveness for normal motion. Lower to 50-60 if the bus adapter "
            "still overheats."
        ),
    )


class MotionConfig(BaseModel):
    """Motion runtime tuning parameters."""

    tick_rate_hz: float = Field(default=50.0, gt=0, description="Control loop frequency")
    default_max_velocity: float = Field(
        default=120.0,
        gt=0,
        description="Fallback velocity budget (deg/s) used to cap spring frequency when a "
        "MotionTarget does not specify its own max_velocity. Acceleration is implicit in "
        "the spring-damper dynamics, so there is no parallel default_max_acceleration here "
        "— the hard acceleration cap lives in SafetyConfig.max_acceleration.",
    )
    default_style: str = Field(
        default="gentle",
        description=(
            "Biomimetic style preset when MotionTarget.style is unset "
            "(gentle|confident|curious|bouncy|hesitant|linear)"
        ),
    )
    default_playback_mode: str = Field(
        default="cleaned",
        description="Default playback mode for play_recording skill (raw|cleaned|expressive). "
        "Applied when the web UI or a tool call does not specify one explicitly.",
    )

    # --- Spring-damper playback settings (stream_frames path) ---
    spring_playback_f: float = Field(
        default=5.0,
        gt=0,
        description="Spring natural frequency (Hz) used during stream_frames playback. "
        "Higher = tighter tracking; lower = more elastic feel.",
    )
    spring_playback_z: float = Field(
        default=0.7,
        gt=0,
        description="Spring damping ratio during stream_frames. "
        "0.7 = slight underdamp (micro-elasticity); 1.0 = critical (no overshoot).",
    )
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

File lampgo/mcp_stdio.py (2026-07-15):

"""Minimal stdio MCP proxy from Codex to the running LampGo daemon.

The transport is deliberately dependency-free: MCP stdio messages are JSON-RPC
objects separated by newlines.  All robot work still goes through the daemon's
authenticated HTTP API and therefore through its normal safety boundaries.
"""

from __future__ import annotations

import asyncio
import json
import os
import sys
from pathlib import Path
from typing import Any

import httpx

from lampgo import personastore

_DEFAULT_DAEMON_TIMEOUT_S = 135.0
_SKILL_INVOKE_TIMEOUT_S = 310.0
_REQUEST_CANCELLED_CODE = -32800

_TOOLS: list[dict[str, Any]] = [
    {
        "name": "lampgo_status",
        "description": "Read the current LampGo robot, motion, and safety status.",
        "annotations": {"readOnlyHint": True, "destructiveHint": False, "openWorldHint": False},
        "inputSchema": {"type": "object", "properties": {}, "additionalProperties": False},
    },
    {
        "name": "lampgo_list_skills",
        "description": "List the LampGo skills that can be invoked safely.",
        "annotations": {"readOnlyHint": True, "destructiveHint": False, "openWorldHint": False},
        "inputSchema": {"type": "object", "properties": {}, "additionalProperties": False},
    },
    {
        "name": "lampgo_invoke",
        "description": "Invoke one registered LampGo skill. Use lampgo_list_skills first when unsure.",
        "annotations": {"readOnlyHint": False, "destructiveHint": False, "openWorldHint": False},
        "inputSchema": {
            "type": "object",
            "properties": {
                "skill_id": {"type": "string", "description": "Exact registered LampGo skill id"},
                "params": {"type": "object", "description": "Skill parameters", "additionalProperties": True},
                "wait": {"type": "boolean", "default": True},
            },
            "required": ["skill_id"],
            "additionalProperties": False,
        },
    },
    {
        "name": "lampgo_camera_snap",
        "description": "Capture the latest image from LampGo's lamp-head camera.",
        "annotations": {"readOnlyHint": True, "destructiveHint": False, "openWorldHint": False},
        "inputSchema": {"type": "object", "properties": {}, "additionalProperties": False},
    },
    {
        "name": "lampgo_ask_user",
        "description": "Ask the user a question through LampGo voice and Web UI, then wait for the reply.",
        "annotations": {"readOnlyHint": False, "destructiveHint": False, "openWorldHint": False},
        "inputSchema": {
            "type": "object",
            "properties": {
                "question": {"type": "string"},
                "options": {"type": "array", "items": {"type": "string"}},
                "timeout_s": {"type": "number", "minimum": 5, "maximum": 600, "default": 120},
            },
            "required": ["question"],
            "additionalProperties": False,
        },
    },
    {
        "name": "lampgo_agent_tasks",
        "description": "List complex tasks currently managed by LampGo.",
        "annotations": {"readOnlyHint": True, "destructiveHint": False, "openWorldHint": False},
        "inputSchema": {"type": "object", "properties": {}, "additionalProperties": False},
    },
]


def _runtime_api_base() -> str:
    override = str(os.environ.get("LAMPGO_API_BASE") or "").strip()
    if override:
        return override.rstrip("/")
    home = Path(os.environ.get("LAMPGO_HOME") or Path.home() / ".lampgo")
    try:
        runtime = json.loads((home / "runtime.json").read_text(encoding="utf-8"))
        api_base = str(runtime.get("api_base") or "").strip()
        if api_base:
            return api_base.rstrip("/")
    except (OSError, json.JSONDecodeError, TypeError):
        pass
    overrides = personastore.get_overrides_toml() or {}
    web = overrides.get("web") if isinstance(overrides.get("web"), dict) else {}
    port = int(web.get("port") or 8420)
    return f"http://127.0.0.1:{port}"


async def _daemon_request(
    method: str,
    path: str,
    payload: dict[str, Any] | None = None,
    *,
    timeout_s: float = _DEFAULT_DAEMON_TIMEOUT_S,
) -> dict[str, Any]:
    token = personastore.get_or_create_local_api_token()
    headers = {"authorization": f"Bearer {token}"}
    try:
        async with httpx.AsyncClient(
            base_url=_runtime_api_base(),
            headers=headers,
            timeout=timeout_s,
            trust_env=False,
        ) as client:
            response = await client.request(method, path, json=payload)
    except httpx.HTTPError as exc:
        return {"ok": False, "error": f"LampGo daemon unavailable: {exc}"}
    try:
        body = response.json()
    except ValueError:
        body = {"ok": False, "error": response.text or f"HTTP {response.status_code}"}
    if response.status_code >= 400 and isinstance(body, dict):
        body.setdefault("ok", False)
        body.setdefault("error", f"HTTP {response.status_code}")
    return body if isinstance(body, dict) else {"ok": False, "error": "invalid daemon response"}
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

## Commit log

2026-03-31 llm agent & camera & frontend (#1)
    * 1
    * agent;camera
    * 优化llm tool
    ---------
2026-04-10 fix: deal with motor 3 problem
    [server.py]
2026-04-10 fix: deal with execute frames plan problem
    [motion.py, trajectory.py]
2026-04-11 feat: try to fix hal problem
    [breathing.py, config.py, hal.py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]
2026-04-16 feat: support safety velocity configable
2026-04-23 update mimo-v2.5 & fix bugs in events
    [config.py, eventstore.py, installer.py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]
2026-04-24 feat: integrate ESP32 wireless camera & microphone with STT pipeline
    - Add ESP32 device discovery (mDNS), health check, and HTTP proxy
    - Add SoftAP WiFi provisioning wizard in frontend
    - Add ESP32 camera as selectable source (topbar popover + settings)
    - Add ESP32 PDM mic WebSocket streaming and push-to-talk capture
    - Extract standalone STT module (MimoSTT) from llm_client, fix
    API endpoint to always use OpenAI-compat path for MiMo ASR
    - Add STT provider/model config and TTS model dropdown in frontend
    - Fallback to local cv2/sounddevice when ESP32 is offline
    Made-with: Cursor
    [config.py, server.py]
2026-04-30 esp32 calling
2026-05-14 Fix ESP32 LiveKit call audio relay
    [server.py]
2026-05-14 Fix ESP32 wake call lifecycle
2026-05-20 Implement ESP32 pairing and LiveKit call safeguards
2026-05-20 Wire LED expressions to ESP32
2026-05-21 Refactor voice, hardware, and RTC interruption handling
2026-05-21 fix: automatically fill in motor port
    [cli.py]
2026-05-21 Fix recovery motion target advancement
    [motion.py, safety.py, server.py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]
2026-05-21 Improve motor calibration startup recovery
2026-05-22 Add configurable LiveKit interruption toggle
2026-05-22 Update the demo action library to adapt to the new structure
    [Stretch.csv, angry_jerk.csv, awkward_pause.csv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]
2026-05-22 Sync ESP32 expression and audio stability updates
    [led.py, recordings.py, server.py]
2026-05-25 fix: Optimize ESP32 control and front-end experience
    [config.py, led.py, server.py]
2026-06-01 Fix web security audit findings
    [config.py, personastore.py, server.py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]
2026-06-04 docs: publish hardware release materials
    [卡口1.STEP, 卡口2.STEP, 底座.STEP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]
2026-06-05 Switch to lampgo-livekit-agent-sdk
2026-06-08 Fix MiMo API base URL
    [config.py, installer.py]
2026-06-08 fix: pin setup-uv action tag
2026-07-07 [codex] improve motor bus diagnostics (#29)
    * fix: improve motor bus diagnostics
    * fix: harden manual motor diagnostics
    - verify torque and lock release before manual calibration
    - open full raw travel range before hand-guided calibration
    - add single-motor Feetech bench diagnostic tool
    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
    [autodetect.py, cli.py, config.py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]
2026-07-07 Add interactive motor setup CLI (#30)
2026-07-07 [codex] add local vision cat teaser debugging (#32)
    * feat: add local vision cat teaser skill
    * feat: add cat teaser vision debug logs
    * feat: refine cat teaser runtime debugging
    - improve local contact detection and suppress lamp self-motion false grabs
    - save cat teaser camera sessions as MP4 with frame event metadata
    - add web duration/color controls plus no-hw local camera fallback
    * fix: address cat teaser review feedback
    * Address cat teaser review feedback
    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
    [server.py]
2026-07-14 Reset built-in recording assets (#38)
    [Stretch.csv, bowing_head.csv, dance1.csv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]
2026-07-15 Replace OpenClaw with local Codex harness (#39)
    * refactor: replace OpenClaw with Codex harness
    * docs: document zero-config Codex integration
    * fix: harden Codex task lifecycle
    * fix: make LampGo MCP cancellation-safe
    * fix: harden local agent API startup
    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
    [autodetect.py, cli.py, config.py]
2026-07-15 Add official recordings and normalize asset paths (#40)
    [伸展.csv, 低头鞠躬.csv, 向前看.csv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]
2026-07-16 Add user-authored LED expression library (#41)
2026-07-20 Harden calibration and LiveKit lifecycle (#42)
    * Guard calibration project paths
    * Harden LiveKit process and call lifecycle
    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
2026-07-20 Fix fail-closed motor startup safety (#43)
    [hal.py, server.py]
2026-07-21 fix: stabilize motor recovery and idle sway (#44)
    Add guarded recovery startup and return-safe execution, prevent idle-sway drift, and make Windows installer output encoding-safe.
    [hal.py, motion.py, safety.py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]
2026-07-21 feat: add LED matrix clock mode (#45)
2026-07-21 feat: enhance LED expression controls (#46)
    Add safe LED brightness controls, per-motion expression composition, local overrides for factory recording metadata, and bulk LED editor frame actions.
2026-07-21 feat: release YareLampGo V2 hardware package
    [卡口1.STEP, 卡口2.STEP, 底座.STEP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]
2026-07-21 docs: link V2 STEP assembly prominently
2026-07-21 docs: add GitHub-readable V2 assembly guide
2026-08-21 feat(windows): add Windows x64 support and hardware flow (#62)
    * feat(windows): add Windows x64 runtime and hardware flow
    * fix(windows): harden IPC and acceptance flow
    * fix(windows): wait for safe process cleanup
    * fix(windows): close remaining review findings
    * fix(windows): clarify cleanup safety diagnostics
    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
    [autodetect.py, cli.py, config.py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]

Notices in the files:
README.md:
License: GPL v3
